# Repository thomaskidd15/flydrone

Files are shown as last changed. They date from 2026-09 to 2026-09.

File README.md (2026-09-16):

# fly-drone

A 3D-printed quadcopter that carries a simulated fruit-fly brain and is left to do whatever the
wiring does. The brain is a leaky integrate-and-fire (LIF) spiking network built from the
FlyWire connectome, running on a Raspberry Pi Pico 2 on the drone. A normal flight controller
keeps the drone in the air; the fly brain only decides where it goes.

```
frame/gen_frame.py      parametric frame generator (manifold3d), two presets
frame/check_2d.py       flat sections of every part, for checking hole placement
frame/stl/pico35/       3.5-inch build for the Pico 2   <- print this one
frame/stl/pi5_5in/      5-inch build sized for a Raspberry Pi 5 (whole brain onboard), for later
```

Regenerate after editing parameters:

```
uv run python frame/gen_frame.py            # pico35
uv run python frame/gen_frame.py pi5_5in
uv run python frame/check_2d.py pico35      # writes sections.png
```

## The frame (pico35)

Fully printed X quad, 180 mm wheelbase, 3.5-inch props. Every part fits a 180 mm bed.

| Part | Qty | Material | Print notes |
|---|---|---|---|
| bottom_plate.stl | 1 | PETG | flat, 4 walls, 40% infill |
| top_plate.stl | 1 | PETG | flat, 4 walls, 40% infill |
| arm_x4.stl | 4 | PETG or PETG-CF | lying flat as exported, 6 walls or 100% infill |
| leg_x4.stl | 4 | PETG or TPU | standing as exported |
| camera_bracket.stl | 1 | PETG | exported on its side, print as is |

Frame weight is about 65 g in PETG. Print two spare arms; they are the crash part.

### Ready-to-print G-code for a Creality K1 (PETG)

Files are in `frame/k1/gcode/`. Use the set that matches the nozzle on your K1.

| Nozzle | File | What | Time | Filament |
|---|---|---|---|---|
| **0.6 mm** | `flydrone_K1_0.6nozzle_plateA_plates_legs_bracket_PETG.gcode` | both plates, 4 legs, camera bracket. 0.25 mm layers, 3 walls, 40% gyroid, 4 mm brim | 2 h 42 min | 56 g |
| **0.6 mm** | `flydrone_K1_0.6nozzle_plateB_arms_PETG.gcode` | 4 arms. 0.25 mm layers, 4 walls, 100% infill, no brim | 1 h 32 min | 37 g |
| 0.4 mm | `flydrone_K1_0.4nozzle_plateA_plates_legs_bracket_PETG.gcode` | same parts, 0.2 mm layers, 4 walls | 2 h 15 min | 55 g |
| 0.4 mm | `flydrone_K1_0.4nozzle_plateB_arms_PETG.gcode` | same arms, 0.2 mm layers, 6 walls | 1 h 27 min | 37 g |

Copy them to a USB stick and print from the K1's screen, or upload through the K1's web
page (Fluidd, `http://<printer-ip>:4408`). Print plate B twice if you want the spare arms.
The G-code is for a stock K1 with the Creality Klipper `START_PRINT` / `END_PRINT` macros,
245 C nozzle, 75 C bed, auxiliary fan off. A K1C or K1 Max can run it as-is too (same
macros, bigger bed on the Max).

The 0.6 mm set uses 0.62 mm lines and 0.25 mm layers, which divides every part thickness
into whole layers (3.5 / 2.5 / 7 / 32 mm), opens the M2 and M3 holes by 0.1 mm because a
fat nozzle closes small holes, and is capped at 12 mm3/s of PETG. Raise `max_vol` in
`frame/k1/slice.py` if your hotend keeps up and you want it faster.

The layouts are also there as STLs if you would rather slice yourself:
`plate_A_plates_legs_bracket.stl`, `plate_B_arms.stl`, or `print_plate_220mm.stl` with
everything in one job. All are already centred on a 220 x 220 bed in print orientation,
no supports needed. The 5-inch preset does not fit one plate; print its parts in two jobs.

To re-slice after changing the frame, `uv run python frame/k1/slice.py` (0.6 mm) or
`uv run python frame/k1/slice.py 0.4`. It uses OrcaSlicer's
command line (portable build in `%LOCALAPPDATA%\Programs\OrcaSlicer-portable`, or on PATH),
flattens Orca's Creality K1 profiles into `frame/k1/profiles/<nozzle>/` and applies the settings below.

The settings baked into that G-code, if you slice it yourself (0.4 mm numbers; the 0.6 mm set uses 0.25 mm layers and one fewer wall):

- 0.2 mm layers, 4 walls on plates, 6 walls or 100% infill on arms.
- 240 to 250 C nozzle, 75 to 80 C bed. Slow it to about 150 mm/s on outer walls; the
  stock 300 mm/s PETG profile is fine for the plates but the arms like it slower and hotter.
- Part fan 30 to 50%. Turn the auxiliary side fan OFF for PETG; it wrecks layer bonding.
  Chamber fan off. Keep the lid on and the door shut.
- PETG bonds too hard to the K1's smooth PEI sheet and can tear the coating. Wipe a thin
  film of glue stick on first as a release layer, or use a textured PEI plate.
- PETG-CF only on a K1C or a K1 with a hardened-steel nozzle; the stock brass nozzle wears
  out. Plain PETG with 6 walls is strong enough for the arms.
- TPU legs are optional. If you try them, 30 to 40 mm/s, retraction 0.5 mm, 220 C.

How it goes together:

- Each arm has a thin tab at the inner end. The tab sits between the bottom and top plates on
  the diagonal "ear" and is held by two M3 x 20 bolts. The arm steps up to full height right
  where the ear ends, so the step locates it against the plate edge.
- The same two bolts continue through the bottom plate into a nut trap in a leg under each
  corner. Slide an M3 nut into the side slot of each leg first.
- The flight controller stack goes on the top plate. Both the 20 x 20 mm (M2) and
  30.5 x 30.5 mm (M3) patterns are there.
- The Pico 2 mounts across the body on four 20 mm M2 standoffs, above the stack.
- The camera bracket bolts to the two M3 holes at the nose of the top plate and hooks over the
  plate edge. The upright has two vertical slots 21 mm apart (fits the Pi Camera Module 3
  pattern) plus zip-tie slots for anything else, tilted 15 degrees up.
- The optical-flow sensor mounts on the tail of the bottom plate, looking down through the
  10 mm hole. There is a generic 15 x 15 mm M2 pattern around it; zip-tie if yours differs.
- Battery goes under the bottom plate, strap through the two slots, between the legs.

Motor pads carry both a 16 x 16 M3 and a 12 x 12 M2 pattern (rotated 45 degrees from each
other), so any 1404 / 1504 / 2004 class motor bolts on.

Clearances as generated: prop disc to camera 13.5 mm, prop disc to Pico 21 mm,
prop tip to prop tip 38 mm.

## Parts to buy (pico35)

| Item | Spec | Notes |
|---|---|---|
| Motors x4 | 1404 ~3800 KV or 1504 ~3000 KV, 4S | 12 x 12 M2 mount is most common in this size |
| Props | 3.5-inch tri-blade, 4 + spares | e.g. Gemfan 3520 or HQProp 3.5 x 2 x 3 |
| Flight controller | 20 x 20 or 30.5 x 30.5, **ArduPilot-supported**, one spare UART | e.g. Kakute H7 Mini (20 x 20) or Matek H743-SLIM (30.5) |
| ESC | 4-in-1, 20 to 35 A, 4S, same mount as the FC | comes as a stack with many FCs |
| Optical flow + rangefinder | Matek 3901-L0X or ARK Flow | indoor position hold, no GPS |
| Battery | 4S 650 to 850 mAh LiPo, XT30 | plus a LiPo charger and a charging bag |
| Radio | ELRS receiver + an ELRS transmitter (RadioMaster Pocket is the cheap one) | needed to arm, to test-fly, and as the kill switch. Not optional |
| Brain | Raspberry Pi Pico 2 (you have it) | powered from the FC's 5 V rail |
| Eye | Arducam HM01B0 mono camera for Pico, or an OV7670; a VL53L1X ToF sensor is the simplest "something is approaching" input | fly eyes are low-res, 320 x 240 is plenty |
| Hardware | 8x M3 x 20 bolts, 8x M3 nuts, 4x M2 x 20 standoffs + screws, FC stack screws/gummies, 200 mm battery strap, zip ties, XT30 pigtail, 20 AWG wire, 35 V 470 uF cap for the ESC | |

Expected all-up weight is around 250 g. 1404 motors on 4S give roughly 1.5 kg of thrust
for that, so it is not marginal. Flight time will be 5 to 7 minutes per battery; the brain
keeps running between flights, flying is just when the battery is in.

## Firmware: the hand-written reflex brain (Pico 2)

`firmware/reflex/` is an Arduino sketch for the Pico 2 (arduino-pico core). It is the
"acts like a fly" version: no connectome, just the two or three reflexes a fly is known for,
written by hand. It exists to debug the eye, the flight-controller link and the flying before
the real fly circuit goes in, and to be the thing the connectome version is compared against.

```
eye (HM01B0 camera, or frames from the PC over USB)
  -> 32 x 24 retina
  -> ReflexBrain        photoreceptor high-pass, Reichardt motion detectors (T4/T5),
                        whole-field motion -> optomotor yaw (HS cells),
                        left/right flow balance -> sidestep (corridor centring),
                        LPLC2-style looming units -> giant fiber -> ESCAPE
  -> DescendingCommand  body-frame velocity + yaw rate
  -> FcLink             MAVLink 2 SET_POSITION_TARGET_LOCAL_NED to ArduPilot, 10 Hz
```

Files:

| File | What |
|---|---|
| `reflex.ino` | main loop: eye -> brain -> flight controller, LED, telemetry on USB |
| `config.h` | pins, camera mode, MAVLink ids, every reflex gain and threshold |
| `brain.h` | `Retina`, `DescendingCommand`, and the `Brain` interface the connectome version will also implement |
| `reflex_brain.h/.cpp` | the reflexes; pure C++, no Arduino dependency |
| `eye.h/.cpp` | `EyeHM01B0` (camera via the vendored PicoHM01B0 PIO/DMA driver) and `EyeUsbSerial` (frames from the PC) |
| `fc_link.h/.cpp` | hand-rolled MAVLink 2 framing for HEARTBEAT and SET_POSITION_TARGET_LOCAL_NED |
| `src/PicoHM01B0/` | camera driver by pmarques-dev, BSD-2, vendored unchanged |

Wiring: camera on GP4 (SDA), GP5 (SCL), GP16 (VSYNC), GP6 (D0), GP14 (PCLK), GP3 (MCLK),
3V3 and GND. Flight controller UART: Pico GP0 (TX) to FC RX, GP1 (RX) to FC TX, GND to GND.
Pico powered from the FC's 5 V pad into VSYS. On the ArduPilot side set that serial port to
`SERIALn_PROTOCOL = 2` and `SERIALn_BAUD = 115`, and fly in GUIDED. The Pico never arms and
never changes mode; your transmitter does that, and its kill switch always wins. If frames stop
arriving for 300 ms the Pico commands hover.

Build and flash (arduino-cli, portable copy in `%LOCALAPPDATA%\Programs\arduino-cli`, or the
Arduino IDE with the "Raspberry Pi Pico/RP2040/RP2350" core installed):

```
arduino-cli compile --fqbn rp2040:rp2040:rpipico2 --output-dir build/pico2 firmware/reflex
arduino-cli upload  --fqbn rp2040:rp2040:rpipico2 -p COM5 firmware/reflex
```

or hold BOOTSEL while plugging the Pico in and copy the `.uf2` onto the drive that appears.
`firmware/reflex/prebuilt/reflex_pico2_camera.uf2` is a ready-built image of the camera
configuration, so you can try it without installing any toolchain.

Testing without hardware, in this order:

1. `uv run python tools/reflex_sim.py` runs the same math in numpy on synthetic stimuli
   (gratings, a looming disc, a passing object, corridors, noise) and writes
   `tools/reflex_sim.png` with PASS/FAIL per case. Tune constants here, then copy to `config.h`.
2. `uv run python tools/host_check.py` compiles the firmware's `reflex_brain.cpp` for the PC
   (with zig, a dev dependency) and checks it gives the same outputs as the Python on identical
   8-bit frames.
3. Set `EYE_SOURCE = EyeSource::UsbSerial` in `config.h`, flash, then
   `uv run python tools/bench_eye.py --port COM5 --stim cycle` streams the synthetic stimuli
   to the Pico over USB and prints the telemetry it sends back. Watch `yaw` flip sign with the
   grating direction and `esc=1` on the looming disc.
4. Camera in, `EYE_SOURCE = EyeSource::Camera`, flash, open a serial monitor at 115200, wave a
   hand at it. Then wire the flight controller.

What it does in the air: hovers, turns to follow motion across its view, drifts away from
the side with more motion, and jumps up and back when something comes straight at it. Set
`CRUISE_VX` above zero and it wanders forward. Everything else is you tuning gains.

## The brain on a Pico 2

The Pico 2 is a microcontroller (two Cortex-M33 at 150 MHz, 520 KB RAM, 4 MB flash), so it
cannot hold the whole 139k-neuron brain. It can hold a real subcircuit of it:

- Flash budget: ~4 MB of connections at 6 bytes each (uint32 target + int16 weight) is about
  600k synapses. RAM budget: ~40k neurons of state. A 5k to 15k neuron visual-to-descending
  subcircuit at 1 ms steps, event-driven, fits with room to spare.
- Core 1 runs the LIF network. Core 0 reads the camera, turns it into ~200 "ommatidia" per
  eye, drives the input neurons, reads the descending neurons, and talks to the flight
  controller.
- The subcircuit is extracted on the PC from the FlyWire v783 release the way
  [mhdsilva/flywire-arduino](https://github.com/mhdsilva/flywire-arduino) does it (looming
  detectors LC4/LPLC2 through interneurons to the giant fiber DNp01), extended with the
  motion pathway (T4/T5 to the lobula plate tangential cells to turning descending neurons).
  [Ranuja01/fly-simulator](https://github.com/Ranuja01/fly-simulator) has a 15k-neuron
  looming-escape cut that is a good size reference.
- Output: giant fiber rate -> escape burst (up and back), left/right descending neuron rates
  -> yaw and sideways velocity, forward descending neurons -> forward velocity. Sent as
  MAVLink velocity setpoints in GUIDED mode (the MAVLink C library runs fine on an MCU).
- The flight controller (ArduPilot, FlowHold or Loiter indoors) does all stabilisation.
  The brain gives decisions; the stabiliser gives reflexes.

If you later want the whole brain onboard, the `pi5_5in` preset carries a Raspberry Pi 5.
[flykeeper](https://github.com/fortunto2/flykeeper) runs the full FlyWire connectome in
real time in Rust on a phone-class ARM chip, so a Pi 5 is realistic.

## Build order

1. Print the frame and buy the parts above.
2. Build it as a normal ArduPilot quad first: bind the radio, calibrate, hover in Stabilize,
   then FlowHold. No brain yet. A drone that hovers on its own is the prerequisite.
3. Wire the Pico 2 to a spare FC UART and prove it can push velocity setpoints in GUIDED mode
   from a hard-coded script, indoors, in a net.
4. Bench the brain on the Pico: run the subcircuit, wave a hand at the camera, watch the giant
   fiber fire on the serial monitor.
5. Plug the brain output into step 3. Fly in a net with a finger on the kill switch.

Expect: nothing without input; a flinch when something approaches; turning toward motion if
the motion pathway is in the cut. Anything beyond that is your decoder, not the fly.

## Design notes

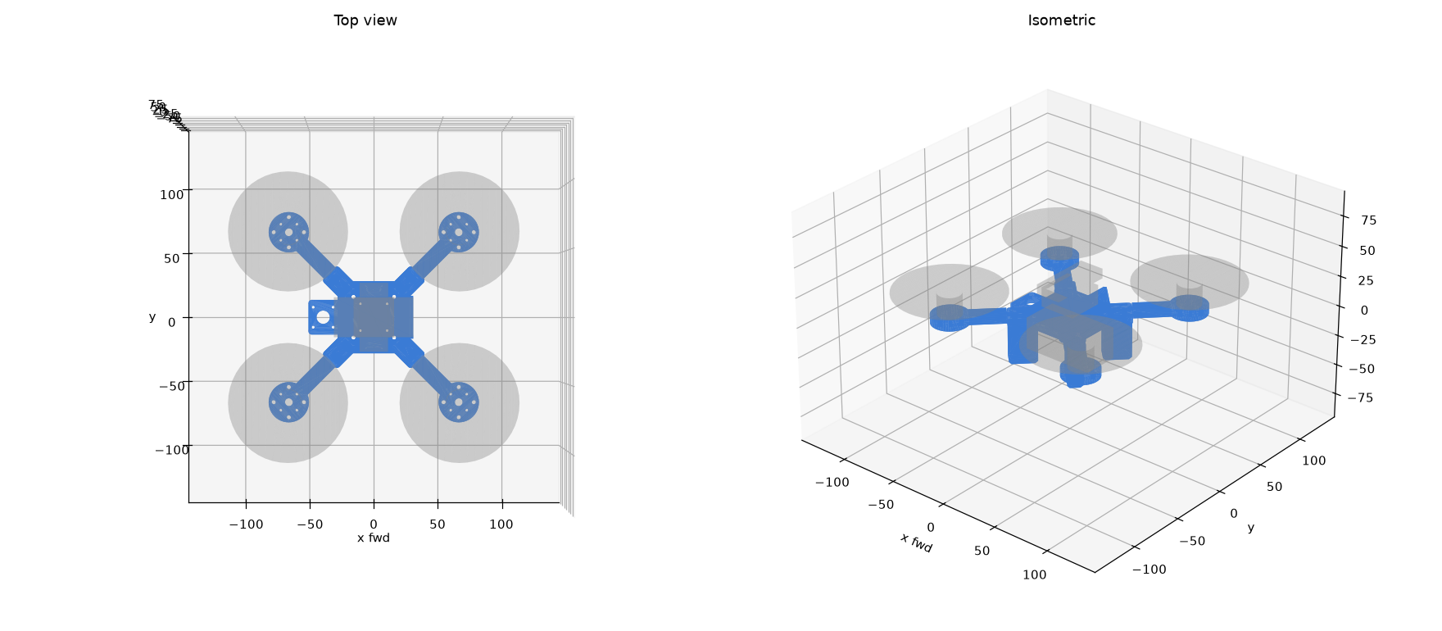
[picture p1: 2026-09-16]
frame/stl/pico35/preview.png

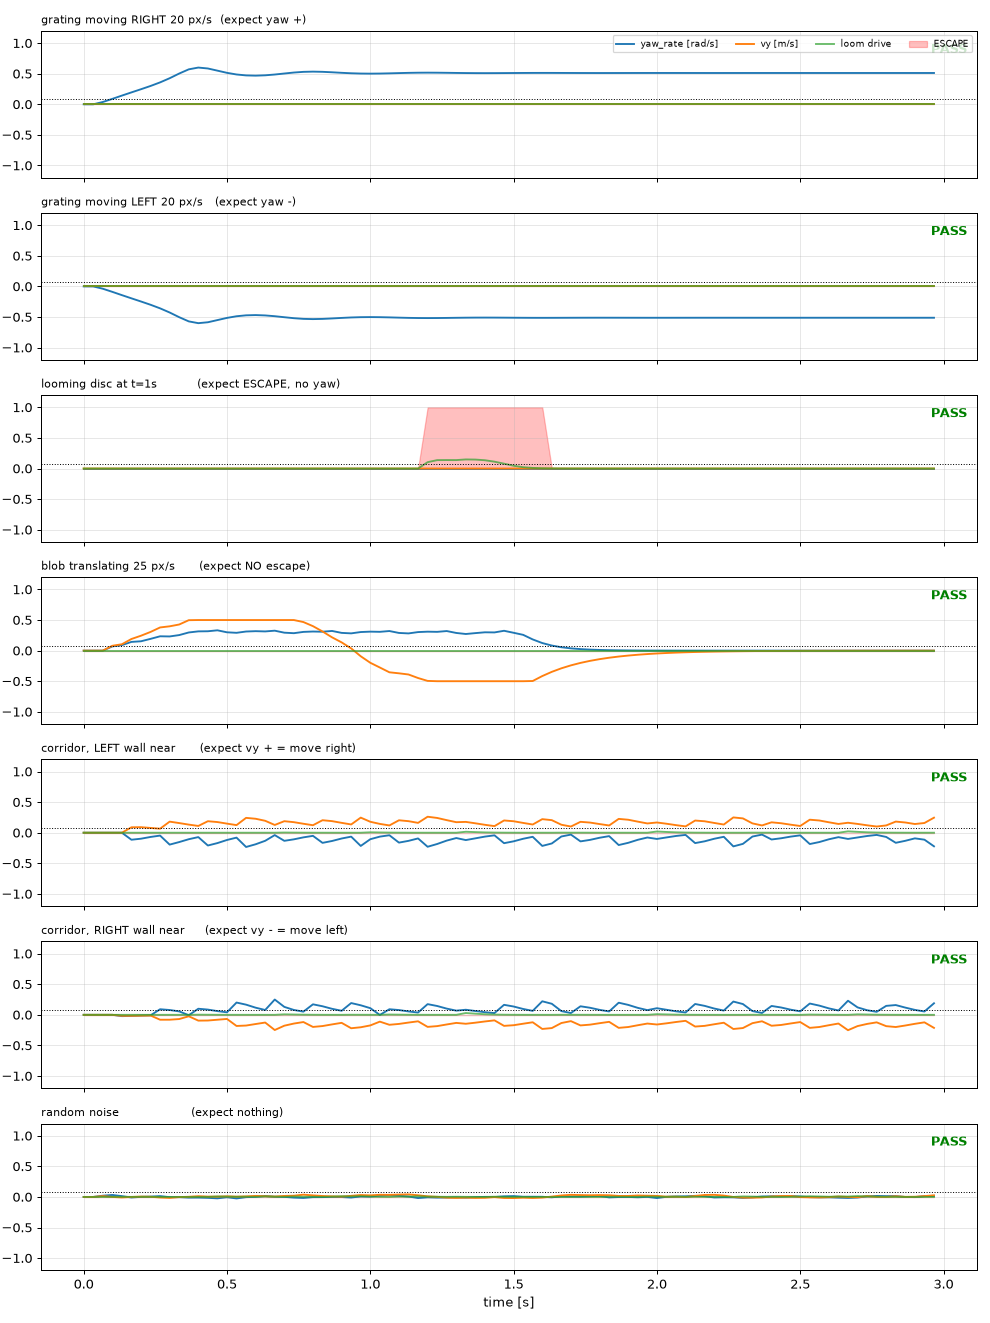
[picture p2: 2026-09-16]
tools/reflex_sim.png

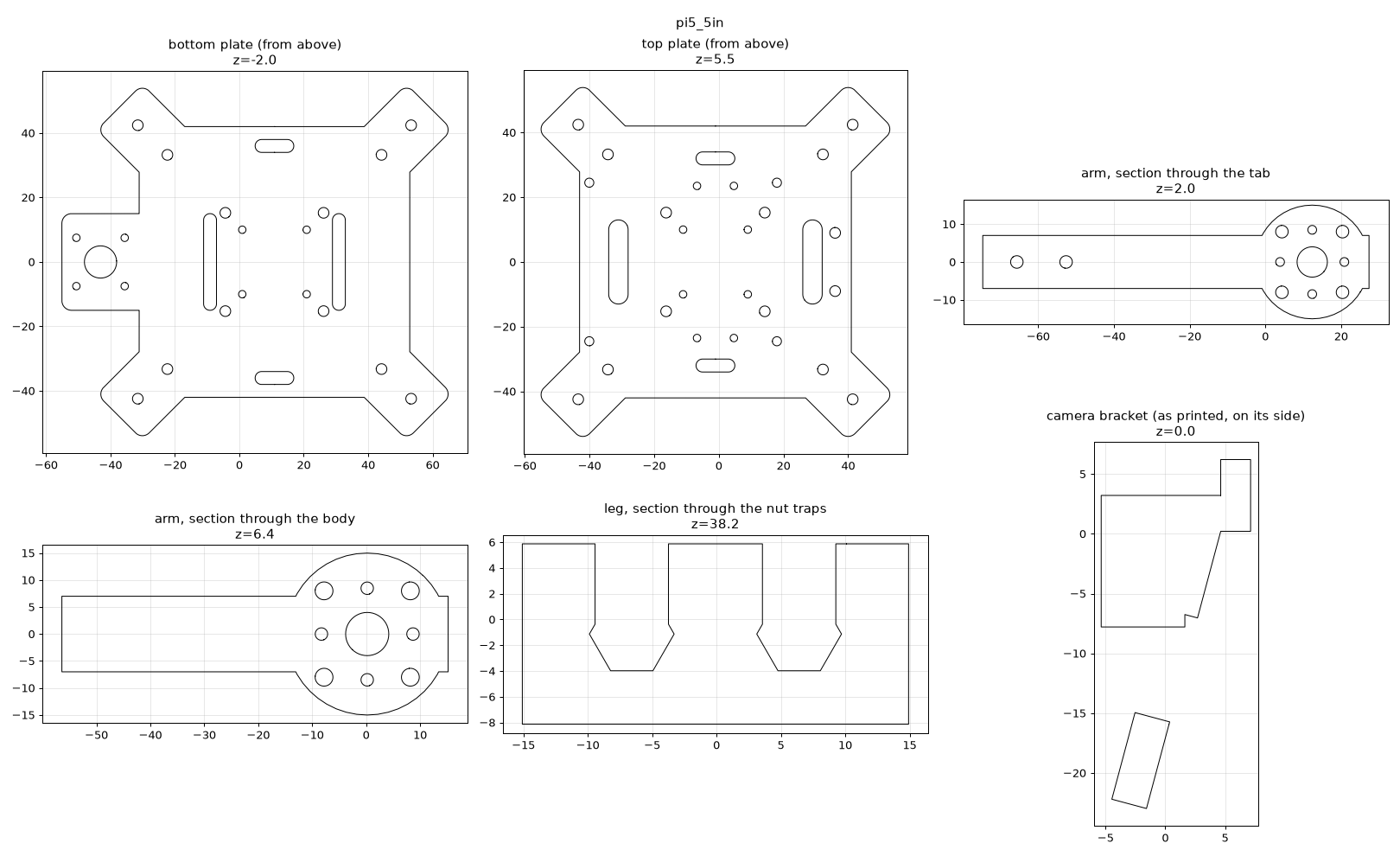
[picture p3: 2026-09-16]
frame/stl/pi5_5in/sections.png

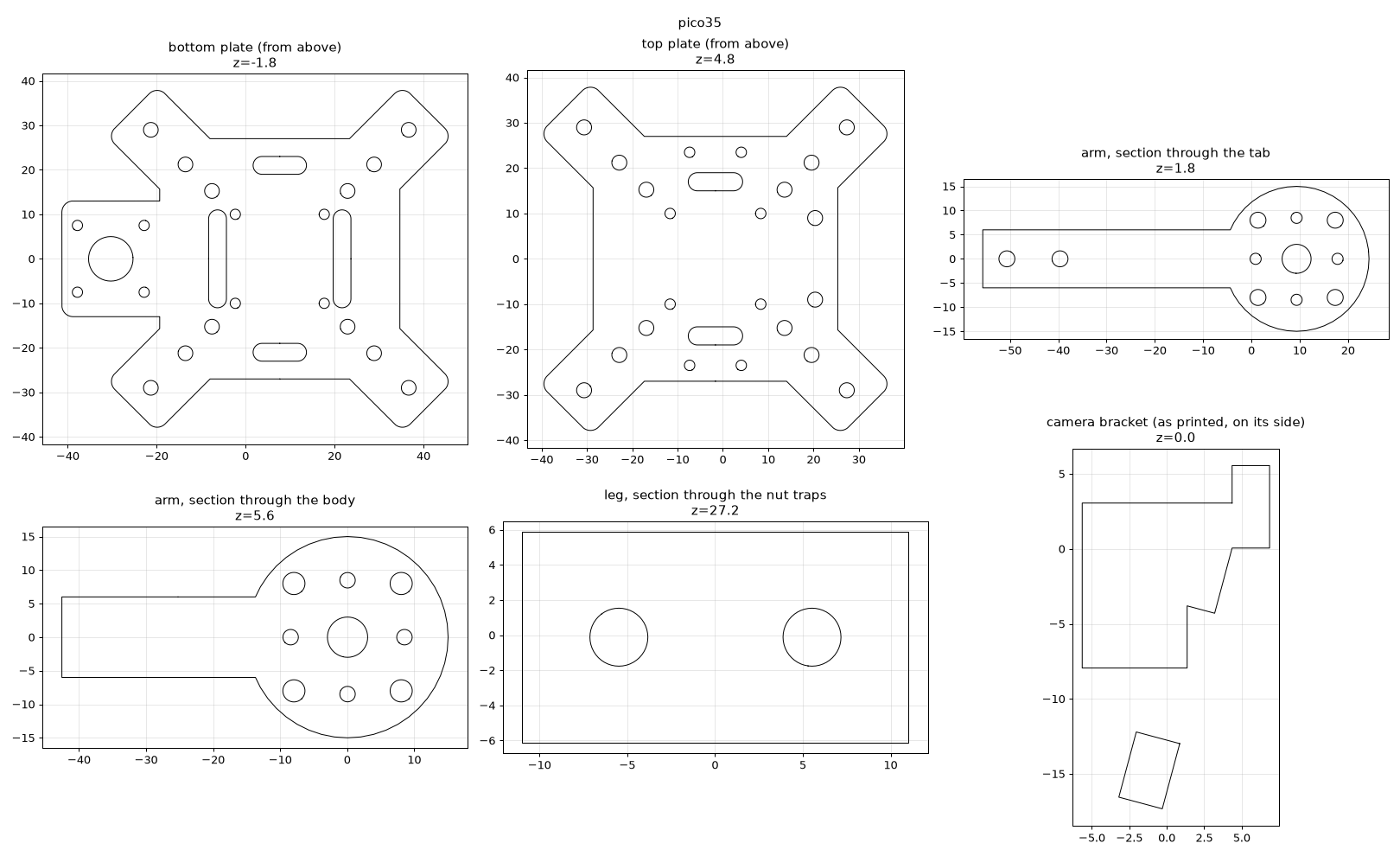
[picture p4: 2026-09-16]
frame/stl/pico35/sections.png

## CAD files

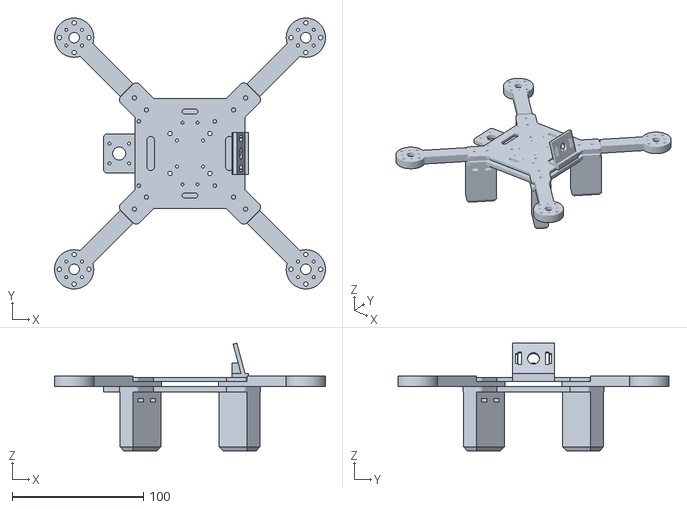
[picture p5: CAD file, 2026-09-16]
frame/stl/pi5_5in/assembly_preview.stl
206.8 x 206.8 x 82.2

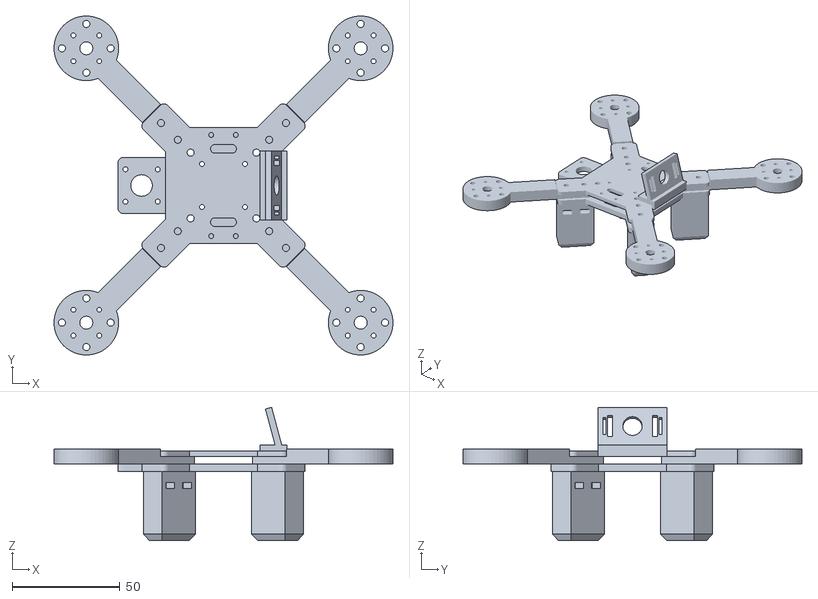
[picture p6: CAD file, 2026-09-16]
frame/stl/pico35/assembly_preview.stl
157.3 x 157.3 x 61.9

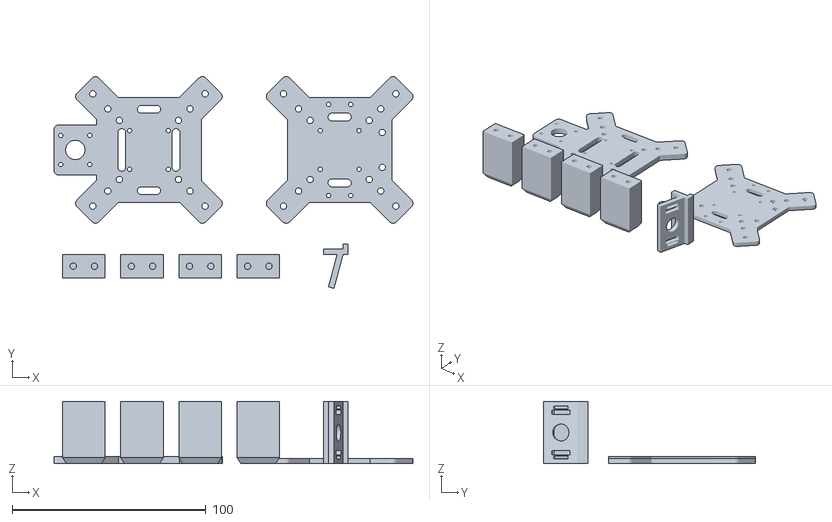
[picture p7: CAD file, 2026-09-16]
frame/stl/pico35/plate_A_plates_legs_bracket.stl
185.3 x 109.3 x 32.0

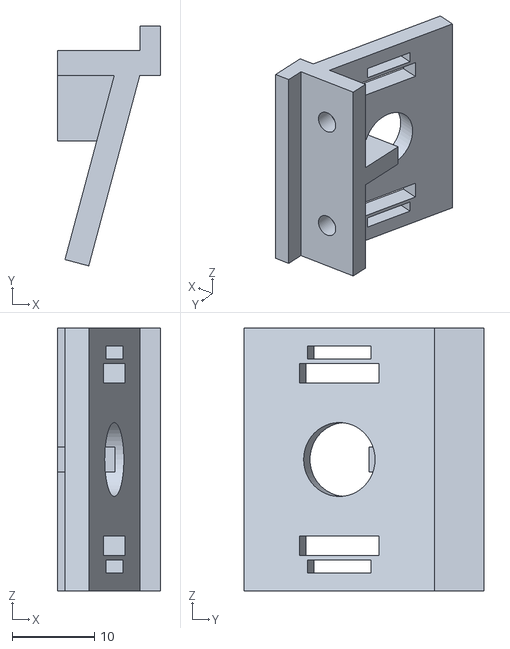
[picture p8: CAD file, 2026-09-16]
frame/stl/pi5_5in/camera_bracket.stl
12.5 x 29.2 x 32.0

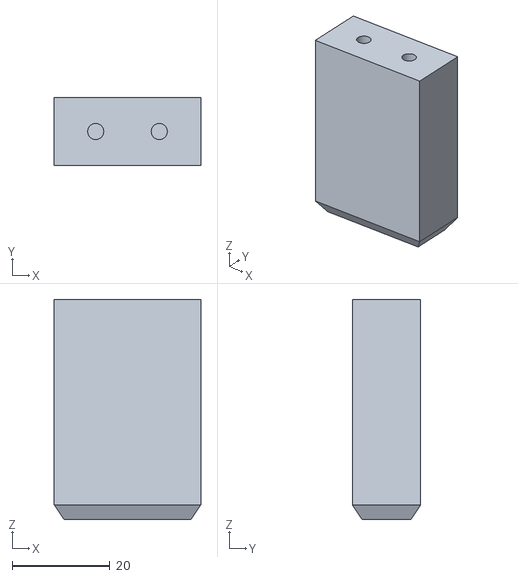
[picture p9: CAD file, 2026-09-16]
frame/stl/pi5_5in/leg_x4.stl
30.0 x 14.0 x 45.0

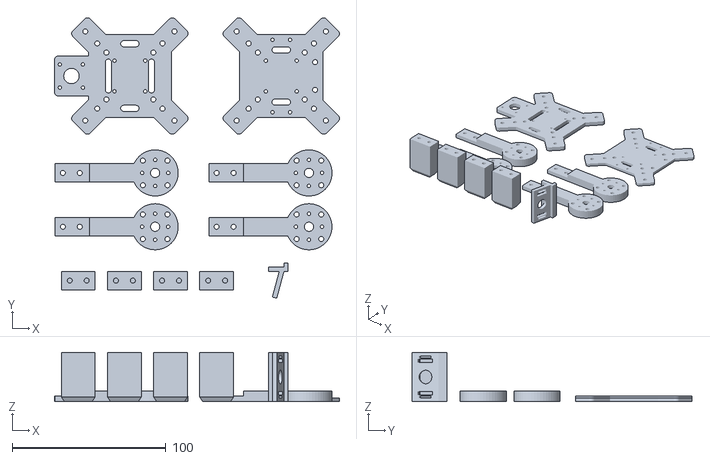
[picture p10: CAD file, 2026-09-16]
frame/stl/pico35/print_plate_220mm.stl
185.3 x 182.3 x 32.0

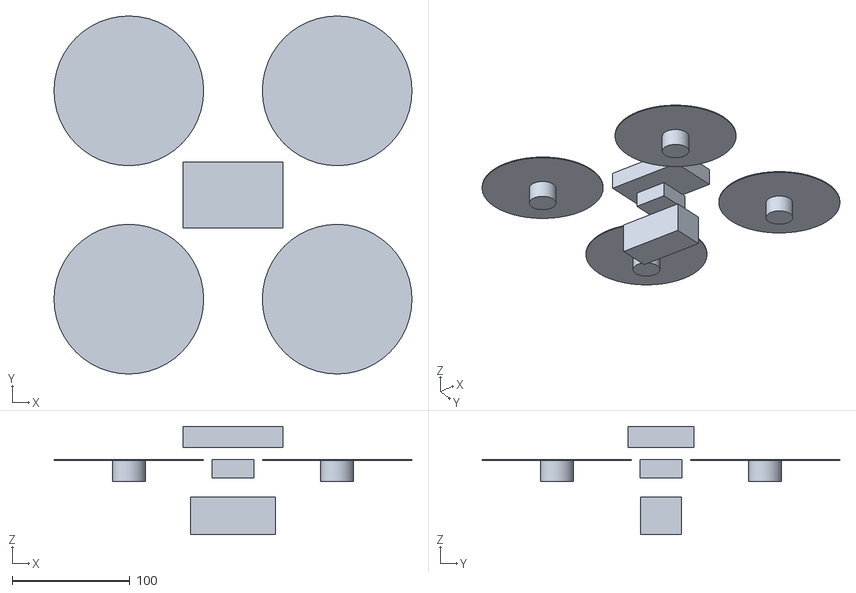
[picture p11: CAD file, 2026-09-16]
frame/stl/pi5_5in/ghost_components.stl
303.8 x 303.8 x 92.0

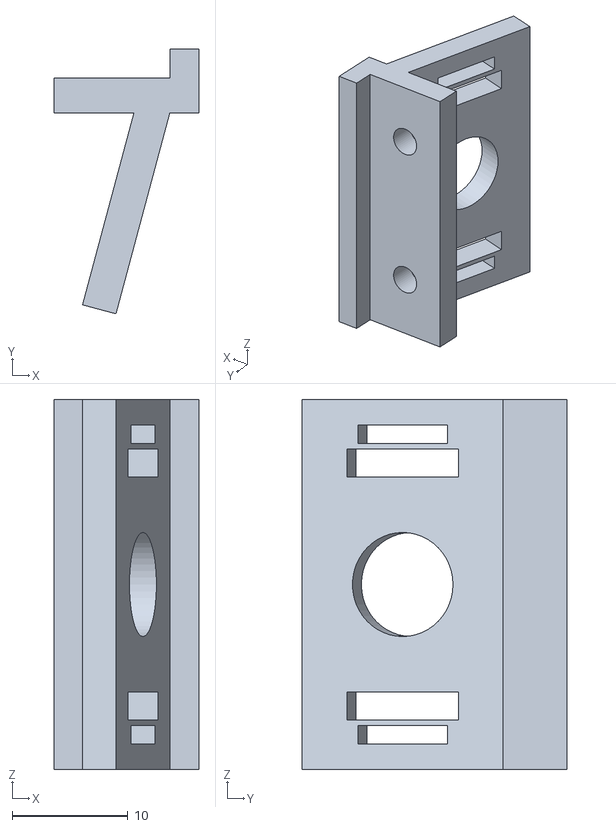
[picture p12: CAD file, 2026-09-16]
frame/stl/pico35/camera_bracket.stl
12.5 x 22.9 x 32.0

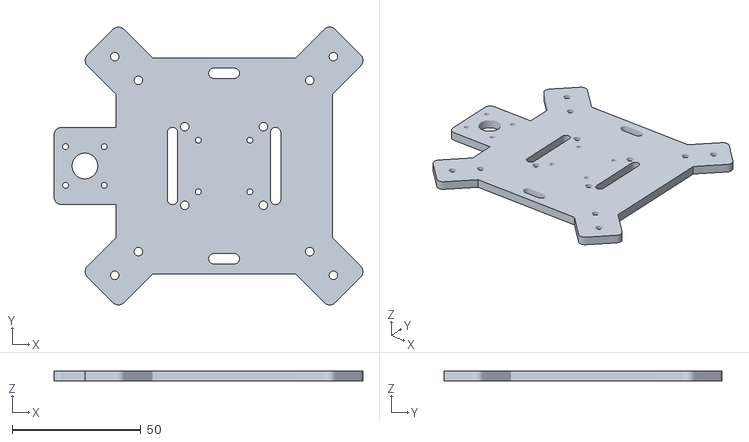
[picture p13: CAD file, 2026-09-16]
frame/stl/pi5_5in/bottom_plate.stl
119.9 x 107.8 x 4.00

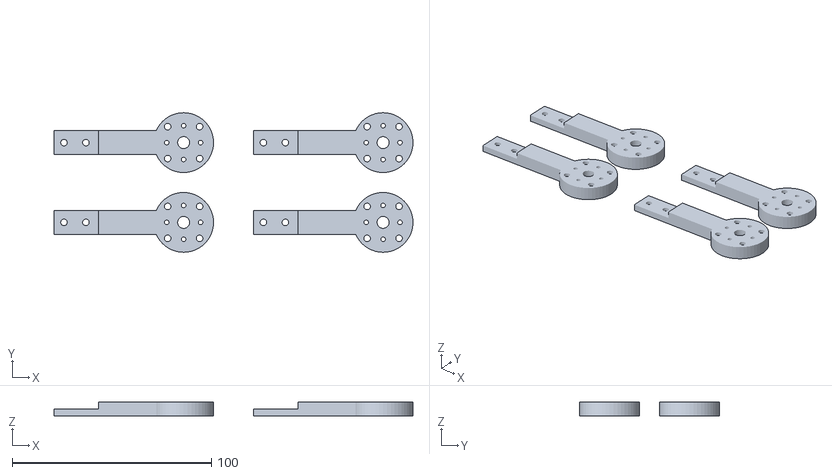
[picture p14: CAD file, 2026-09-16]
frame/stl/pico35/plate_B_arms.stl
180.0 x 70.0 x 7.00

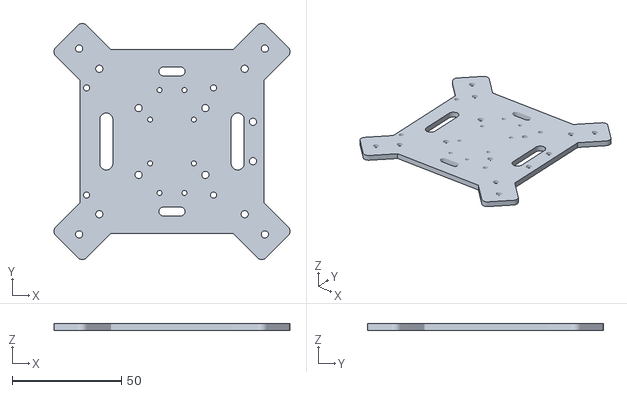
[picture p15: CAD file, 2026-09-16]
frame/stl/pi5_5in/top_plate.stl
107.8 x 107.8 x 3.00

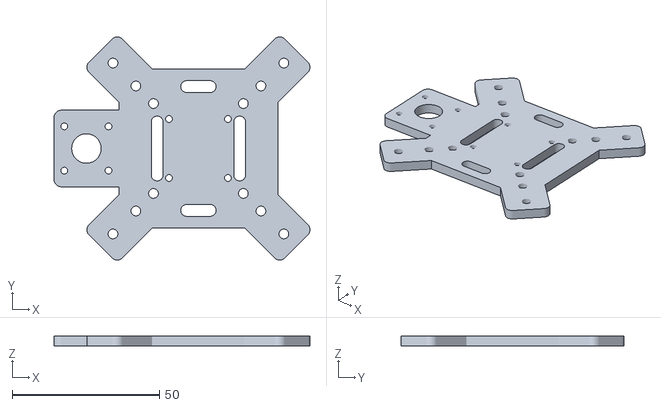
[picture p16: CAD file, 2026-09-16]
frame/stl/pico35/bottom_plate.stl
86.9 x 75.7 x 3.50

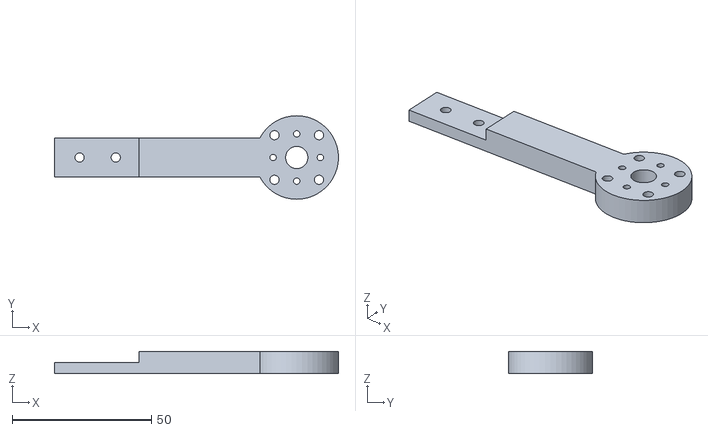
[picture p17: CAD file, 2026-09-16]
frame/stl/pi5_5in/arm_x4.stl
102.0 x 30.0 x 8.00

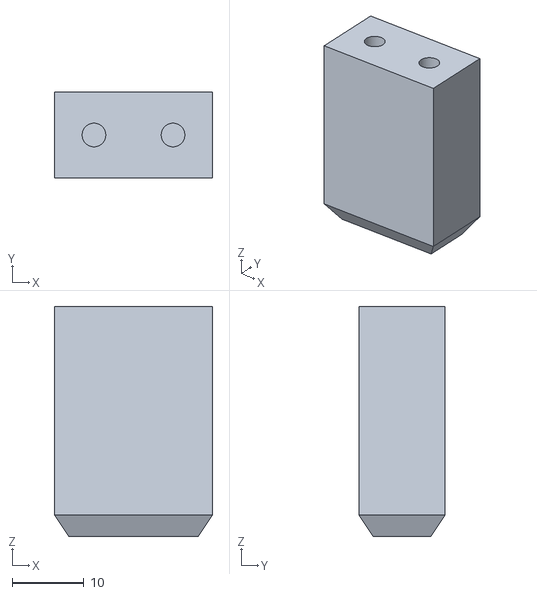
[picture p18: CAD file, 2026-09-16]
frame/stl/pico35/leg_x4.stl
22.0 x 12.0 x 32.0

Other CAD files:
frame/stl/pico35/ghost_components.stl
frame/stl/pico35/arm_x4.stl
frame/stl/pico35/top_plate.stl

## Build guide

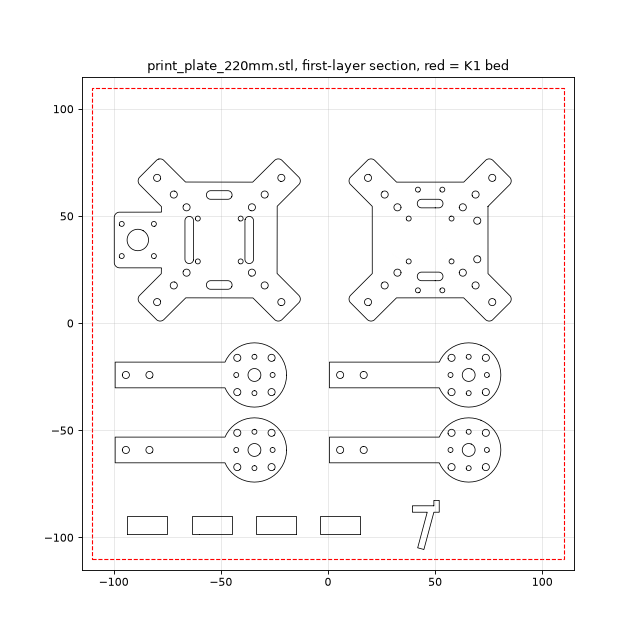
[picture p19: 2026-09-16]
frame/stl/pico35/print_plate_layout.png

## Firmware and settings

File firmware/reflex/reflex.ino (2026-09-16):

// fly-drone reflex firmware for a Raspberry Pi Pico 2.
//
//   eye (camera or USB frames) -> brain (hand-written fly reflexes) -> flight controller (MAVLink)
//
// Board: "Raspberry Pi Pico 2" from the arduino-pico core (Earle Philhower).
// Build:  arduino-cli compile --fqbn rp2040:rp2040:rpipico2 firmware/reflex
// Flash:  hold BOOTSEL, plug in, copy the .uf2, or arduino-cli upload -p COMx
//
// The flight controller must be armed and put in GUIDED mode from the transmitter; the Pico
// never arms or changes modes. If the eye stops delivering frames the Pico commands hover.
#include "config.h"
#include "brain.h"
#include "reflex_brain.h"
#include "eye.h"
#include "fc_link.h"

static EyeHM01B0 eye_cam;
static EyeUsbSerial eye_usb;
static Eye* eye = nullptr;
static ReflexBrain brain;
static FcLink link;
static Retina retina;
static DescendingCommand cmd;

static bool eye_ok = false;
static uint32_t last_frame_ms = 0, prev_frame_ms = 0;
static uint32_t last_setpoint_ms = 0, last_hb_ms = 0, last_tel_ms = 0;
static uint32_t frames = 0, frames_at_last_tel = 0;

void setup() {
  pinMode(LED_PIN, OUTPUT);
  Serial.begin(115200);

  Serial1.setTX(FC_UART_TX);
  Serial1.setRX(FC_UART_RX);
  link.begin(Serial1, FC_BAUD);

  eye = (EYE_SOURCE == EyeSource::Camera) ? static_cast<Eye*>(&eye_cam) : static_cast<Eye*>(&eye_usb);
  eye_ok = eye->begin();
  brain.reset();

  // three quick blinks = booted; a long one = eye failed
  for (int i = 0; i < 3; i++) { digitalWrite(LED_PIN, HIGH); delay(80); digitalWrite(LED_PIN, LOW); delay(80); }
  if (!eye_ok) { digitalWrite(LED_PIN, HIGH); delay(1000); digitalWrite(LED_PIN, LOW); }
}

void loop() {
  const uint32_t now = millis();

  // 1. senses -> brain, whenever a new frame lands
  if (eye_ok && eye->poll(retina)) {
    float dt = prev_frame_ms ? (now - prev_frame_ms) * 0.001f : (1.0f / CAM_FPS);
    if (dt < 0.005f) dt = 0.005f;
    if (dt > 0.2f) dt = 0.2f;
    cmd = brain.step(retina, dt);
    prev_frame_ms = now;
    last_frame_ms = now;
    frames++;
  }

  // 2. brain -> flight controller at a steady rate; hover if the eye has gone quiet
  if (now - last_setpoint_ms >= SETPOINT_PERIOD_MS) {
    last_setpoint_ms = now;
    const bool eye_fresh = eye_ok && (now - last_frame_ms) <= EYE_TIMEOUT_MS && frames > 0;
    if (eye_fresh) link.sendVelocity(cmd, now);
    else link.sendHover(now);
  }
  if (now - last_hb_ms >= HEARTBEAT_PERIOD_MS) {
    last_hb_ms = now;
    link.sendHeartbeat();
  }

  // 3. LED: solid during an escape, slow blink while frames are flowing, off otherwise
  const bool eye_fresh = eye_ok && (now - last_frame_ms) <= EYE_TIMEOUT_MS && frames > 0;
  digitalWrite(LED_PIN, cmd.escape ? HIGH : (eye_fresh && ((now / 500) % 2 == 0)) ? HIGH : LOW);

  // 4. telemetry on USB for tools/bench_eye.py and for watching in a serial monitor
  if (now - last_tel_ms >= TELEMETRY_PERIOD_MS) {
    const float fps = (frames - frames_at_last_tel) * 1000.0f / (float)(now - last_tel_ms);
    last_tel_ms = now;
    frames_at_last_tel = frames;
    Serial.printf("T t=%lu eye=%s fps=%.1f yaw=%.3f vx=%.2f vy=%.2f vz=%.2f esc=%d loom=%.3f yawsig=%.3f fl=%.3f fr=%.3f mav=%lu\n",
                  (unsigned long)now, eye_ok ? eye->name() : "none", fps,
                  cmd.yaw_rate, cmd.vx, cmd.vy, cmd.vz, cmd.escape ? 1 : 0,
                  cmd.dbg_loom, cmd.dbg_yaw_sig, cmd.dbg_flow_l, cmd.dbg_flow_r,
                  (unsigned long)link.framesSent());
  }
}

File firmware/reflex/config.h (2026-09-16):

// Everything you might want to change lives here.
#pragma once
#include <stdint.h>

// ---------------------------------------------------------------- retina
// The camera frame is block-averaged down to this many "ommatidia". A fly has ~800 per eye;
// 32 x 24 for both eyes together is plenty for the reflexes and cheap to process.
constexpr int RET_W = 32;
constexpr int RET_H = 24;

// ---------------------------------------------------------------- eye source
enum class EyeSource { Camera, UsbSerial };
// Camera:    Arducam HM01B0 module on the pins below.
// UsbSerial: frames pushed from the PC by tools/bench_eye.py (no camera needed).
constexpr EyeSource EYE_SOURCE = EyeSource::Camera;

// Arducam HM01B0 "camera module for Raspberry Pi Pico". GPIO numbers, not board pin numbers.
constexpr int CAM_SDA   = 4;
constexpr int CAM_SCL   = 5;
constexpr int CAM_VSYNC = 16;
constexpr int CAM_D0    = 6;      // 1-bit data bus on this module
constexpr int CAM_PCLK  = 14;
constexpr int CAM_MCLK  = 3;      // the Pico generates the camera clock on this pin
constexpr float CAM_FPS = 30.0f;  // 30 divides 60 Hz mains, so auto-exposure does not flicker
constexpr bool CAM_FLIP_H = false;
constexpr bool CAM_FLIP_V = false;

// ---------------------------------------------------------------- flight controller link
// MAVLink 2 over UART0. Wire Pico GP0 (TX) -> FC RX, GP1 (RX) <- FC TX, GND-GND.
// On the ArduPilot side: SERIALn_PROTOCOL = 2 (MAVLink2), SERIALn_BAUD = 115.
constexpr int FC_UART_TX = 0;
constexpr int FC_UART_RX = 1;
constexpr uint32_t FC_BAUD = 115200;
constexpr uint8_t MAV_SYSID = 1;            // same vehicle
constexpr uint8_t MAV_COMPID = 191;         // MAV_COMP_ID_ONBOARD_COMPUTER
constexpr uint8_t MAV_TARGET_SYS = 1;
constexpr uint8_t MAV_TARGET_COMP = 1;      // MAV_COMP_ID_AUTOPILOT1
constexpr uint32_t SETPOINT_PERIOD_MS = 100;   // 10 Hz velocity setpoints (ArduPilot needs >= ~3 Hz)
constexpr uint32_t HEARTBEAT_PERIOD_MS = 1000;
constexpr uint32_t EYE_TIMEOUT_MS = 300;    // no fresh frame for this long -> command hover

// ---------------------------------------------------------------- reflex gains
// These mirror Params in tools/reflex_sim.py. Change them there first, look at the plot,
// then copy here.
constexpr float TAU_HP       = 0.30f;   // s, contrast high-pass (photoreceptor adaptation)
constexpr float TAU_DELAY    = 0.04f;   // s, Reichardt delay arm
constexpr float CONTRAST_EPS = 1e-3f;
constexpr float K_YAW        = 4.0f;    // rad/s per unit normalised horizontal motion
constexpr float K_CENTER     = 3.0f;    // m/s per unit left-right flow imbalance
constexpr float TAU_LOOM     = 0.06f;   // s, low-pass on the looming drive
constexpr float LOOM_THRESH  = 0.08f;   // sim: looming disc peaks ~0.15, nothing else above 0.03
constexpr float ESCAPE_S     = 0.4f;
constexpr float REFRACTORY_S = 1.5f;
constexpr float MAX_YAW_RATE = 1.0f;    // rad/s
constexpr float MAX_V        = 0.5f;    // m/s
constexpr float CRUISE_VX    = 0.0f;    // m/s forward drift when nothing is happening. 0 = hover.
constexpr float YAW_FILT_S   = 0.1f;
constexpr float VY_FILT_S    = 0.2f;

// ---------------------------------------------------------------- misc
constexpr int LED_PIN = 25;             // on-board LED: heartbeat blink, solid during ESCAPE
constexpr uint32_t TELEMETRY_PERIOD_MS = 200;   // "T ..." lines on USB serial

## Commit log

2026-09-16 Fly-brain drone: parametric 3D-printed frame, STLs, and build plan
    Two presets in frame/gen_frame.py (manifold3d CSG):
    - pico35: 3.5-inch, 180 mm wheelbase, Raspberry Pi Pico 2 onboard
    - pi5_5in: 5-inch, 250 mm wheelbase, Raspberry Pi 5 on the top deck
    Generated STLs, preview and section drawings under frame/stl/<preset>/.
    README covers construction, parts list, the Pico 2 brain plan and build order.
    [arm_x4.stl, assembly_preview.stl, bottom_plate.stl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]
2026-09-16 Add open_in_blender.py: load a preset's STLs into Blender with a framed 3/4 view
2026-09-16 One-job print plate for 220 mm beds, K1 print settings, camera bracket sits flat on its side
    [assembly_preview.stl, camera_bracket.stl, print_plate_220mm.stl]
2026-09-16 K1 G-code: two ready-to-print jobs, OrcaSlicer CLI slicing script, flattened K1 profiles
    - frame/k1/slice.py flattens Orca's Creality K1 (0.4) + Generic PETG profiles, applies our
    settings (4 walls/40% gyroid for plates+legs+bracket, 6 walls/100% for arms, 245/75 C,
    aux fan off) and slices via --slice 0 --export-3mf with --arrange 0.
    - plate_A / plate_B STLs centred on a 220 mm bed; camera bracket gusset removed (floating
    when printed on its side).
    - G-code checked: toolpaths inside 0..220, START_PRINT/END_PRINT present.
    [assembly_preview.stl, camera_bracket.stl, machine_k1.json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]
2026-09-16 Treat gcode/stl as binary in git
2026-09-16 K1 G-code for the 0.6 mm nozzle; slice script is nozzle-aware
    0.6 set: Orca "Creality K1 (0.6 nozzle)" profile, 0.62 mm lines, 0.25 mm layers so every part
    thickness is whole layers, 3 walls on plates / 4 on arms, holes opened 0.1 mm, 12 mm3/s cap.
    0.4 set kept and renamed with the nozzle in the filename.
    [machine_k1.json]
2026-09-16 Pico 2 reflex firmware: hand-written fly reflexes, camera eye, MAVLink link, sim + host cross-check
    firmware/reflex (arduino-pico, Raspberry Pi Pico 2):
    - ReflexBrain: photoreceptor high-pass, Reichardt EMDs, optomotor yaw, left/right flow
    centring, 3x3 LPLC2-style looming array -> giant-fiber escape with refractory period
    - EyeHM01B0 via vendored PicoHM01B0 (BSD-2) PIO/DMA driver, 164x122 -> 32x24 retina;
    EyeUsbSerial for desk testing with frames from the PC
    - FcLink: hand-rolled MAVLink 2 HEARTBEAT + SET_POSITION_TARGET_LOCAL_NED (body-frame
    velocity + yaw rate) to ArduPilot GUIDED at 10 Hz, hover failsafe on eye timeout
    - Brain interface (brain.h) is the seam where the connectome br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
    [PicoHM01B0.cc, bench_eye.py, config.h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]
2026-09-16 README: fix arduino-cli path
